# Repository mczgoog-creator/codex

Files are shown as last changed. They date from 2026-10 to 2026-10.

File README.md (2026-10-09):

# DRV8701 双电机驱动板 · Rev B

**12 V、39×60 mm、4 层、1.6 mm** 双电机驱动板。Rev B 重新安排了两路半桥、去耦和功率回路，并加入 TPS25910 主电源控制。每段线路、过孔和铜区均按明确坐标人工规划，未使用自动布线或路径搜索。

[网页端 KiCad 导入包](downloads/DRV8701_12V_KiCad5_Import.zip) · [完整工程和资料 ZIP](downloads/DRV8701_12V_EasyEDA_Pro.zip) · [工程说明](hardware/drv8701-dual-12v/README.md)

## 在嘉立创 EDA 专业版中打开

网页端请下载 **`DRV8701_12V_KiCad5_Import.zip`**，在开始页选择 **「导入 KiCad」**，直接选择 ZIP。按[官网指引](https://prodocs.lceda.cn/cn/import-export/import-kicad/index.html)，导入副本采用真实 KiCad 5.1 格式，并通过 KiCad 自带归档功能打包。步骤和导入后检查见[网页导入说明](hardware/drv8701-dual-12v/IMPORT_IN_WEB_PRO.md)。

原始 KiCad 9 工程和自带库也随包保存。`EasyEDA_Pro/DRV8701_DUAL_12V.eprj3` 是另供 V4.1+ 离线／半离线桌面客户端使用的文件夹工程；需保留整个目录，不能当作网页 `.epro` 文件导入。

## 本版变化

- 四组高边源极与低边漏极相邻，通过局部宽铜连接相节点；功率转层采用四孔阵列。公共供电在 C15 正极处汇合并向两路分配。
- 泵和内部电源去耦至芯片的关键连接留在顶层；VM 先到 C3/C10，再到芯片 VM 脚。SH 源参考采用独立细线返回高边源极焊盘。
- 新增 U6 TPS25910、SW1 和五个配套无源件。SW1 控制主电源，原 U5 继续控制 DRV8701 的 nSLEEP。原 38 个元件的取值保留；原有脚网络仅 P2.1 从 VM 改为新增电源入口 VM_RAW。

主电源连续额定 5 A，R12=40.2 kΩ 对应手册限流 4.5–5.5 A。主开关关闭时芯片仍消耗约 2.5 mA 典型／4 mA 最大，分压另约 90 µA；不提供电池物理隔离或反向电流阻断。开启主电源前应保持两路桥关闭，VM 稳定后再使能，详见[首次上电步骤](hardware/drv8701-dual-12v/FIRST_POWER_ON.md)。

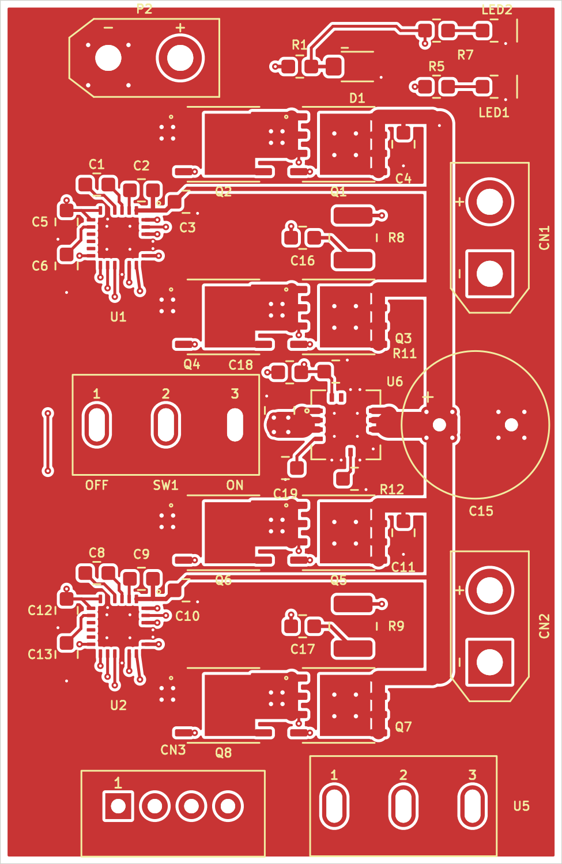
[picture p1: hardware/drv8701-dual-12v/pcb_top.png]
Rev B PCB 顶层预览


## 文件与检查边界

- [原理图 PDF](hardware/drv8701-dual-12v/DRV8701_DUAL_12V_schematic.pdf)、[PCB 各层检查图](hardware/drv8701-dual-12v/PCB_layers_review.pdf)
- [元件清单](hardware/drv8701-dual-12v/components.csv)、[采购约束](hardware/drv8701-dual-12v/procurement_notes.csv)
- [布局与电流路径说明](hardware/drv8701-dual-12v/source/engineering_review.md)、[主电源手册核对](hardware/drv8701-dual-12v/source/tps25910_power_control_review.md)
- [原图保留范围核对](hardware/drv8701-dual-12v/validation/rev_b_original_source_contract.json)、[交付检查记录](hardware/drv8701-dual-12v/validation/final_delivery.json)
- [独立布局几何检查](hardware/drv8701-dual-12v/validation/layout_geometry_audit.json)、[最后丝印与铜线复核](hardware/drv8701-dual-12v/validation/rev_b_final_silk_cleanup.json)、[Rev B 工程审计](hardware/drv8701-dual-12v/validation/rev_b_engineering_audit.json)

Rev B 共 **45 个元件、38 个网络、203 个唯一物理引脚／211 个焊盘实例、592 段线路、151 个过孔、12 个铜区**。冻结后的 KiCad 9 源板 **DRC 0 违规／0 未连接，原理图 ERC 0 错误／0 警告**。独立几何检查通过：14 条关键去耦连接均在顶层，最长 2.9713 mm；丝印与焊盘／过孔碰撞为 0，审核范围内的直角／锐角弯折为 0。

网页导入副本已通过真实 **KiCad 5.1.9：ERC 0 错误／0 警告，PCB DRC 0 错误／0 未连接**；45 个元件、38 网、203 脚逐值逐脚一致。PCB 检查已重填全部铜区并检查走线与填铜。副本的 624 段线路中，新增 32 段完全位于原 MOS 漏极焊盘铜内，新增实际铜面积为 0；原 592 段线路、151 孔、211 焊盘及 12 铜区保留。见[旧版最终等价核对](hardware/drv8701-dual-12v/validation/legacy5_final_pcb_equivalence.json)。

源软件检查不替代专业版实际导入检查。弯折统计排除同网焊盘／过孔内部和真实分支结点，具体范围见几何报告。五页 PCB 检查图、分层 PDF 及顶／底 SVG／PNG 均按冻结源板重新导出，来源 SHA 见[预览导出记录](hardware/drv8701-dual-12v/validation/preview_exports.json)。

桌面原生工程的[静态转换审计](hardware/drv8701-dual-12v/EasyEDA_Pro/native-final-audit.json) 已通过：元件／引脚／线路／过孔及 12 个填充铜区均与冻结源板对应，官方工程结构检查 0 错误／0 警告。未运行真实专业版桌面客户端，网页用户仍使用上面的 KiCad 导入 ZIP。

**真实嘉立创网页导入／DRC、样板通电和温升测试尚未完成。** 导入会重新铺铜，需复核四层各 35 µm 铜、功率铜区和规则。原图的 100 nF 电荷泵／内部电源去耦、较弱齐纳供电、IDRIVE 设置和无 GND 的控制插座仍保留，并在工程说明中列出。MOS 原厂手册已读取，采购需匹配普通 SOP Advance 封装；手册没有提供推荐 PCB 焊盘图。

## 来源与许可证

官方开源转换／校验工具保留各自的 Apache-2.0／MIT 许可证；上游地址与精确版本见[版本记录](hardware/drv8701-dual-12v/tools/easyeda-native/upstream-versions.json)。这些工具许可证不自动覆盖电路设计、第三方封装或厂商 PDF。原图、封装和手册来源见工程说明。

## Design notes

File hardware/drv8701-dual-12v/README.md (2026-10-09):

# DRV8701 双电机驱动板 · Rev B · 12 V

依据用户原始《8701驱动板（无电流检测2.0）.pdf》重建。本版重新安排半桥功率器件、去耦、供电和回流，并按用户后续要求加入主电源控制。**原 38 个元件的取值全部保留；原有引脚唯一授权网络变化是 P2.1 从 VM 改接 VM_RAW。** 原图其余连接保留，新增七件：U6、SW1、R10–R12、C18、C19。核对见 [rev_b_original_source_contract.json](validation/rev_b_original_source_contract.json)。

PCB 每个元件位置、线路、过孔和铜区边界均人工规划，未使用嘉立创自动布线器、其它自动布线器或路径搜索。脚本按明确坐标生成线路；铺铜填充只是按既定边界生成铜区。

## 打开工程与交付文件

用户使用嘉立创 EDA 专业版**网页端**。主要入口为 **`DRV8701_12V_KiCad5_Import.zip`**：在网页开始页选择 **「导入 KiCad」**后直接选择 ZIP。依据[官网指引](https://prodocs.lceda.cn/cn/import-export/import-kicad/index.html)，导入副本采用真实 KiCad 5.1 格式并由 KiCad 自带归档功能打包。步骤见 [IMPORT_IN_WEB_PRO.md](IMPORT_IN_WEB_PRO.md)。

原始 KiCad 9 源文件与库保留。桌面入口 `EasyEDA_Pro/DRV8701_DUAL_12V.eprj3` 由官方转换器及独立后处理生成，另供专业版 V4.1+ 离线／半离线客户端使用，需保留整个目录；不能当作网页 `.epro` 文件导入。

**尚未在真实嘉立创 EDA 专业版完成导入和 DRC。** 导入会重建铜区，需复核板框、叠层、功率铜区和设计规则。桌面文件的 schema／真实导出模板单位差异见 `tools/easyeda-native/RESEARCH.md`；首次打开应确认实际尺寸和规则值。

|文件|用途|
|---|---|
|`DRV8701_DUAL_12V.kicad_sch/.kicad_pcb/.kicad_pro`|Rev B 可编辑原理图、PCB、规则|
|`DRV8701_Custom.kicad_sym`、`DRV8701_Custom.pretty/`|本地符号及封装；配套库表同目录保存|
|`KiCad_Import_5/`|真实 KiCad 5.1 格式的网页导入副本|
|`imports/DRV8701_12V_KiCad5_Import.zip`|专用网页导入 ZIP|
|`EasyEDA_Pro/`|另供新版桌面客户端使用的文件夹原生工程|
|`DRV8701_DUAL_12V_schematic.pdf`|原理图阅读版|
|`PCB_layers_review.pdf`、`pcb_top/bottom.svg/.png`|从源 CAD 导出的各层检查图与顶底预览；底层 PNG/SVG 已镜像，按从底面观察显示|
|`components.csv`、`procurement_notes.csv`|元件值、封装及采购额定参数|
|`source/source_netlist.json`|原始 PDF 独立复核网表，作为原图基准保留|
|`validation/rev_b_original_source_contract.json`|原图取值、连接与授权主电源差异核对|
|`final_drc.json`、`validation/schematic_erc.json`|冻结后的 KiCad 9 DRC 与原理图 ERC|
|`validation/layout_geometry_audit.json`|独立读取实际 PCB 的路径、弯折、过孔与丝印检查|
|`validation/rev_b_final_silk_cleanup.json`|最终丝印调整与唯一最后铜线修改范围|
|`validation/rev_b_engineering_audit.json`|本版功率网络、填铜与工程审计|
|`validation/preview_exports.json`|本版预览与各层 PDF 的源板 SHA／导出记录|
|`source/engineering_review.md`|本版布局与电流路径说明|
|`source/tps25910_power_control_review.md`|主电源芯片手册、启动／限流／关闭状态核对|
|`FIRST_POWER_ON.md`|首次上电和两级开关操作步骤|
|`footprint_geometry.json`、`manual_routes.json`|封装依据及人工规划线路记录|
|`scripts/generate_schematic.py`、`tools/build_board.py`|原理图及明确坐标的 PCB 生成程序|
|`validation/`|本版最终检查记录|

用 KiCad 9 打开 `.kicad_pro` 即可读取同目录库。重建程序会覆盖其负责的设计文件，运行前应保存手工编辑副本。

## 尺寸、电流与布局

仅采用用户电机表格的 **12 V** 条件：每路较高档额定 0.4 A、堵转 1.8 A；电机路径按每路 1.8 A，公共供电／回流按合计 3.6 A 规划。堵转值用于短时最大电流初筛，不表示允许持续堵转。

本版 **39×60 mm、4 层、标称 1.6 mm**，元件全在顶面。四铜层均 **35 µm（1 oz）**，孔电阻计算假设成品孔铜至少 20 µm。名义叠层：两面阻焊各 0.01 mm、四铜层各 0.035 mm、两段半固化片各 0.20 mm、中芯板 1.04 mm，总厚 1.60 mm；板厂应据实际材料匹配成品规格。普通 R/C/LED 为 0603，R8/R9 为 1210，新增 C18 为 0805；没有小于 0402 的贴片。

|通路|本版设计|
|---|---|
|P2 至 U6、U6 至 C15 及两路主供电|外层公共主干 1.80 mm；C15 正极为汇合与分配点|
|In2.Cu 并行供电|4.6 mm VM 公共铜带与局部宽铜支路|
|高边 MOS 漏极|短 1.0 mm 外层支路，并由内层铜和四孔阵列连接裸露漏极焊盘|
|高边源极至低边漏极|相邻封装间的局部顶层宽铜，四组半桥均按相同结构安排|
|电机连接器|0.70 mm 外层主线，每个相节点配四孔功率阵列|
|低边 MOS 源极|短支线接本地宽铜，四孔阵列接地；F.Cu／In1.Cu／B.Cu 地铜提供并行回流|
|U6 IN／OUT|各三个并联引脚，每脚短 0.45 mm 连接接入公共铜；不是单根 0.45 mm 线路承担 3.6 A|
|信号与驱动支路|约 0.20–0.30 mm；这些线路不承担电机主电流|

IPC-2221 经验式 `I=k×ΔT^0.44×A^0.725`（A 为平方 mil）用于初筛。35 µm 铜、约 10°C 温升时，外层 1.8 A／3.6 A 线宽约 0.676／1.758 mm，内层约 1.76／4.57 mm，因此内层公共 VM 铜带取 4.6 mm。该经验式不计算实际板上的电流密度、开关波形或温升，成品仍需测量。

C15 安排在受控 VM 供电汇合处，两路从其正极向外分配。每组高／低边 MOS 旋转后令高边源极紧邻低边裸露漏极，以宽铜连接相节点。泵／内部电源去耦至芯片的关键连接留在顶层，VM 电源先进入 C3/C10 再到 VM 引脚；C4/C11 位于功率母线旁。SH 源参考采用独立细线返回高边源极焊盘，但栅极和参考线仍有转层，14 条关键连接静态路径的最大长度为 2.9713 mm、0 转层；GH1 约 19.22 mm、GH2 约 13.56 mm 且仍有转层，不能宣称全部驱动回路已最小化或开关振铃已验证。

制造规则最小间距／线宽 0.15 mm，普通信号孔 0.45/0.20 mm，最小钻孔 0.20 mm、最小环宽 0.10 mm。具体功率孔阵列和最终几何以本版检查报告为准。

## 主电源与接口

|位号|功能与引脚|
|---|---|
|P2|12 V 电源 XT30：1=VM_RAW 正极，2=GND|
|U6|TPS25910RSAR：IN 1/2/3=VM_RAW；OUT 10/11/12=VM；中心焊盘接 GND|
|SW1|主电源开关：2=PWR_EN，3=GND，1=NC；接通 2–3 时 U6 导通|
|U5|原 DRV8701 使能：2=NSLEEP，3=齐纳 3V3，1=NC；断开 2–3 时为休眠档|
|CN1/CN2|左／右电机 XT30：1=L_A/R_A，2=L_B/R_B|
|CN3|1=R_EN，2=R_PH，3=L_PH，4=L_EN；原图未设置 GND 引脚|

CN3 没有公共地针脚，控制器 GND 必须另外连接 P2 的 GND。SW1 是主供电控制，U5 是驱动芯片睡眠控制，二者不能混用。

TPS25910 工作电压 3–20 V、IN/OUT 绝对最大 22 V；本工程仅按 12 V 使用。连续额定 5 A，R12=40.2 kΩ、1% 对应限流 **4.5 A 最小／5 A 典型／5.5 A 最大**。这只是公共电源故障控制，不是两路电机各自的电流测量或斩波限流。3.6 A 时芯片导通损耗约 0.38 W 典型／0.54 W 最大，需要焊实中心接地焊盘并验证温升。

EN 为低电平有效。SW1 接通将 EN 拉地；断开时 R10=100 kΩ、R11=33 kΩ 分压产生约 2.98 V 高电平关闭。**关闭时 U6 自身仍消耗 2.5 mA 典型／4 mA 最大，分压另约 90 µA**。C15 储能和电机回馈可能使 VM 暂时有电；TPS25910 本身没有反向电流阻断，因此主开关不是电池物理隔离。长期存放应拔掉电源。

C19=10 nF 对 12 V 的理想上升时间约 **11.1 ms 典型**，按手册 8–15 µA 驱动电流初算约 **8.2–15.3 ms**。实际电容、输入电源、限流和热保护会改变或延长启动。手册 12 V 启动最小负载电阻为 12 Ω，接有 C15 时可用启动负载进一步减少；因此**开启 SW1 前保持 U5 休眠并令两路 EN=0，VM 稳定后再使能电机**。不得把典型上升时间当作控制器等待的保证值。

## PWM 与原图保留问题

按用户确认的 **不高于 20 kHz EN PWM** 使用，PH 固定方向。R8/R9=100 Ω、C16/C17=100 nF 串联 RC 保留；电阻采用 **1210、至少 0.5 W**。12 V／20 kHz 充分充放电模型每路约 0.288 W 上界、50% 占空比约 0.244 W。PH 周期翻转会产生更大的跨端阶跃，不能沿用该热假设。

|项目|保留的原图与影响|
|---|---|
|C2/C9 VCP–VM|100 nF，TI 推荐 1 µF；须检查泵纹波与驱动欠压|
|C5/C12 AVDD、C6/C13 DVDD|100 nF，TI 推荐 1 µF；须核查 LDO 稳定性和纹波|
|C1/C8 CPH–CPL|100 nF，与 TI 推荐值一致|
|VM 旁路|保留 100 nF 与公共 C15=470 µF；须测供电／再生电压|
|VREF／IDRIVE|各自接 AVDD；约 25/50 mA 源／灌，关闭高边 VDS 过流检测|
|SP／SN|接 GND；没有电机电流采样及各路可设斩波限流|
|nFAULT／SNSOUT／SO|原图 NC，控制器不能由这些脚接收原驱动器故障或采样信息|
|10 kΩ／齐纳 3V3|12 V 下假定 3.3 V 时总馈电约 0.87 mA；还供 LED 与 nSLEEP，须实测低电流工作点|
|CN3|无 GND 引脚，控制器另行共地|

布局重排和新增主开关没有修正上述原值与原连接。首次验证内容及顺序见 [FIRST_POWER_ON.md](FIRST_POWER_ON.md)。

## 焊接与采购复核

DRV8701 是 4×4 mm RGE24 VQFN、0.5 mm 脚距，中心地焊盘必须焊实。U6 是带中心地焊盘的 RSA16 VQFN。建议焊膏、预热和热风／手动回流；仅烙铁处理外围脚不能保证中心焊接。未填孔热过孔会吸锡，需检查浮高和空洞。

TPH1R403NL：1/2/3=S、4=G、5/6/7/8=D，中心裸露金属同属 D；高边裸露焊盘为 VM，低边为相节点，不能当作接地散热焊盘。原厂 **2026-04-14 Rev.3.0.A** 已读取：VDS 30 V、VGS ±20 V；10 V 下 RDS(on) 典型 1.2 mΩ／最大 1.4 mΩ，Qg 典型 46 nC、Qgd 典型 4.3 nC。引脚与普通 SOP Advance 的机械图已核对，详见 [原厂核对](source/tph1r403nl_manufacturer_review.md)。

该手册 p8 普通 SOP Advance 与 p9 SOP Advance(N) 不同，采购需匹配 p8。手册未提供推荐 PCB 铜焊盘图，外围 0.5×1.2 mm 焊盘是本设计尺寸。典型 Qg／原图 25/50 mA 的估算不替代最坏公差及实测 VGS。

SS12D10G4 的用户实测脚宽 1.3 mm、厚 0.8 mm，使用 2.3×1.1 mm 槽孔。C18 采购目标为 4.7 µF／50 V／X7R／0805，**须按具体料号的 DC 偏压曲线核对 12 V 下有效电容≥1 µF**；当前没有对某个采购料号完成该曲线验证。XT30、XH 实物外形、极性与 U6 钢网要求也应按采购品及厂商图复核。

## 来源与验证边界

- 原始 PDF：用户提供，见 `source/original_schematic.pdf`；原始网表见 `source/source_netlist.json`。
- TI DRV8701：[原厂手册](https://www.ti.com/lit/ds/symlink/drv8701.pdf)，SLVSCX5B，附原厂镜像 PDF `source/TI_DRV8701_SLVSCX5B.pdf`；镜像来自 [Tinkerforge](https://github.com/Tinkerforge/performance-dc-bricklet/blob/master/datasheets/drv8701.pdf)。
- TI TPS25910：`source/TI_TPS25910_SLUSAR6D.pdf` 与 EVM 手册；参数、封装及页码见 [主电源核对](source/tps25910_power_control_review.md)。
- Toshiba：[精确型号原厂 PDF](https://toshiba.semicon-storage.com/info/TPH1R403NL_datasheet_en_20191030.pdf?did=14296&prodName=TPH1R403NL)，本包为 Rev.3.0.A；MOS 封装几何另参考 [zdxddmx/smartcar-hardware](https://github.com/zdxddmx/smartcar-hardware) 的同型号原生库，交叉核对 [CaptainJaja/DRV8701_2Motors](https://github.com/CaptainJaja/DRV8701_2Motors)。未复用其它工程的 PCB 布局或布线。
- 官方转换／验证工具保留原许可证，上游 URL／commit 见 `tools/easyeda-native/upstream-versions.json`。

本版为 **45 个元件、38 个网络、203 个唯一物理引脚／211 个焊盘实例**，592 段人工指定线路、151 个过孔、12 个铜区。源 KiCad 9、KiCad 5 导入副本和桌面原生工程分别核对，各自结果保存于 `validation/`、`KiCad_Import_5/validation/` 和 `EasyEDA_Pro/native-*.json`，不沿用 Rev A 检查成绩。

冻结后的源板 KiCad 9 **DRC 0 违规、0 未连接**，原理图 **ERC 0 错误、0 警告**。独立 [布局几何审计](validation/layout_geometry_audit.json) 通过，14 条关键去耦连接全部顶层且 0 转层，最长 2.9713 mm；丝印与焊盘／过孔碰撞 0，审核范围内直角／锐角弯折 0。弯折分类排除同网焊盘／过孔内以及真实分支结点。最终 PCB SHA256 为 `daa3c5be68e8667a06f6da7ec5fd3c1238de758fb6982bcae6e130e6b8204989`。

[最终丝印复核](validation/rev_b_final_silk_cleanup.json) 确认最后铜修改仅把 C18.1 至 U6 IN 汇流处的一段 VM_RAW 输入颈缩由 0.9 mm 加宽到 1.8 mm；其它焊盘、过孔和铜区边界未在该步骤改变。R10 位号移至底层，其余位号在顶层；主电源／休眠开关说明与板名位于背面，开关 ON 仍对应右侧／pin3。功率铜区和原图差异另见 [Rev B 工程审计](validation/rev_b_engineering_audit.json)。

桌面原生工程 [native-final-audit.json](EasyEDA_Pro/native-final-audit.json) 已通过静态转换检查，源板 SHA 与冻结文件一致。45 件／38 网／203 个唯一脚、592 段线路、151 孔及 12 个实际填充铜区逐项对应；四层、叠层厚度、区优先级及直接焊盘连接参数保留。格式检查 4096 条外层记录有效，未映射类型／未解释失败均为 0；已知 schema 与真实导出差异单列，官方工程结构检查 0 错误／0 警告。**这些是文件级检查，实际专业版桌面打开与 DRC 未执行。**

网页副本已由真实 **KiCad 5.1.9** 检查：原理图 **ERC 0 错误／0 警告**，PCB **DRC 0 错误／0 未连接**。检查已重填全部铜区，并开启全部走线错误及走线与填铜检查。45 件及原值、38 网、203 个唯一脚（194 连接、9 NC）逐项一致。副本保留源板 592 段线路、151 孔、211 焊盘和 12 铜区，另加 32 段完全在 MOS 既有漏极焊盘铜内的连接段，使旧版识别原有铜连通；副本共 624 段、新增实际铜面积 **0.0 mm²**。新旧填铜缓存随软件版本不同，按源区边界／参数在旧版实际重填；审计见 [legacy5_final_pcb_equivalence.json](validation/legacy5_final_pcb_equivalence.json)。

原理图 PDF、五页 PCB 各层检查 PDF、各层独立 PDF 与顶／底 SVG／PNG 均已更新为冻结 Rev B，源板 SHA 与导出方式见 [preview_exports.json](validation/preview_exports.json)。底层预览已镜像；层 PDF 由源 CAD SVG 经矢量转换生成，以保留完整板框。

本交付没有生产下单或 Gerber 制造放行。**真实专业版导入、铺铜／DRC，以及样板启动、开关波形、温升和短时堵转测试未完成。** 静态格式或铜几何核对不能代替这些实测。

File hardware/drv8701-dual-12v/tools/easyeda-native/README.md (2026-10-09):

# 原生工程生成与审计工具

Node.js 18+。最终工程已生成时，不需要运行这些工具即可用专业版打开工程。

这些脚本使用嘉立创／EasyEDA 官方 KiCad→`.eprj3` 转换器，再做有记录的字段纠正。所有 PCB 走线、过孔、铺铜都来自已完成的源板；脚本不调用自动布线，也不寻找连线路径。

准备字段验证器的依赖：在本目录运行 `npm ci --ignore-scripts`。实际转换器无 npm 依赖。然后运行：

```sh
bash run-native-conversion.sh /path/to/drv8701-dual-12v /path/to/new-native-output
```

输出目录必须是新的。源文件包含 `DRV8701_DUAL_12V.kicad_sch` 与 `DRV8701_DUAL_12V.kicad_pcb`；逐物理脚独立网表默认读取 `validation/expected_physical_pin_nets.json`，器件位号和值读取 `design_netlist.json`。所有数量均从本次源设计计算，适用于新增主电源控制的 Rev B。脚本检查失败会以非零状态停止。

工程必须保留完整目录。这份 `.eprj3` 是可选桌面交付：解压后，在支持该目录格式的专业版 V4.1+ 离线／半离线桌面客户端打开 `DRV8701_DUAL_12V.eprj3`，不要单独移动索引文件。网页端使用主交付 KiCad 5 ZIP 和官方“导入 KiCad”入口，不能把 `.eprj3` 放入 `.epro` 文件选择器。实际客户端 CLI 验证需要 V4.1.60+。

验证层次：

- `native-format-validation.json`：外层记录与当前官方字段 schema；真实导出与最新 schema 的已知差异单列，未修改 schema。
- `native-net-equivalence.json`：原生原理图逐脚网络与独立源表一致性。
- `native-pcb-equivalence.json`：原生 PCB 逐脚网络、所有直线走线端点／宽度／层别、过孔几何、铺铜边界和已填多边形与 KiCad 源一致性；逐区比较 priority→POUR.order、直连／热焊模式、间距、热焊间隙／桥宽、最小细度和孤岛模式。
- 该 PCB 报告还独立比较本次源板全部焊盘的尺寸、世界坐标、角度、圆角、圆孔／长槽、镀孔状态及铜层，并比较物理叠层厚度。
- 焊盘阻焊／锡膏扩展按源板保存并逐项检查，不沿用官方转换器默认2mil阻焊扩展。
- `native-library-link-equivalence.json`：本次全部组件的原理图／PCB共用器件、符号、封装、Unique ID；所需库均内嵌。
- `native-final-audit.json`：动态核验全部位号、原理图与PCB器件值、物理脚与命名网数量，并绑定本次源文件 SHA-256。PCB器件值保存为独立 Name 属性，避免共用同一符号／封装的不同阻容值丢失。
- `native-conversion-evidence.json`：旋转纠正与焊盘世界坐标逐个验算。
- `native-design-rules.json`：0.15 mm 最小铜间距／线宽、0.20 mm 最小孔径、0.10 mm 环宽、0.45/0.20 mm 默认过孔，以及 VM/VM_RAW／电机输出／栅极／信号默认线宽。

文件格式审计不等同于实际客户端打开或其 DRC。本云环境没有安装嘉立创专业版桌面客户端，实际打开与 DRC 尚未运行。叠层 thickness 和 RULE 长度的最新官方字段说明与官方 V4.1.36 真实导出模板单位口径存在差异；生成文件采用与真实导出模板一致的 PCB mil 编码。请在客户端确认 1.6 mm／四层／每层35 µm铜，以及上述规则显示值。详见 `RESEARCH.md`。

Rev B 所有区域采用统一的 0.15 mm 间距和直接焊盘连接，适配脚本用官方默认 COPPER 规则保存该连接模式；thermal_gap=0.25 mm、thermal_bridge_width=0.5 mm 同时保留，但在直连模式下不生效。全部区域移除所有无连接孤岛，面积阈值因此不生效。源区参数若不一致、使用面积阈值移除孤岛或未支持的网格填充，脚本会明确拒绝。POUR.width 保留官方转换器说明的真实导出 mm 特例，SOLID fineness 与热焊长度采用 PCB mil；这些显示和重新铺铜行为仍需实际桌面客户端核验。

官方工具来源与锁定版本记录在 `upstream-versions.json`，对应许可证保留在各供应目录。上游源代码没有修改；本目录顶层脚本是独立后处理和审计代码。

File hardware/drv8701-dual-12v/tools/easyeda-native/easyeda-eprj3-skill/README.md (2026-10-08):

# easyeda-eprj3-skill

> 用 AI 或几条 Node 命令，生成可在 EasyEDA Pro（嘉立创 EDA 专业版）直接打开的 `.eprj3` 工程。

[English version](README_en.md) · **当前版本：1.7.3** · [更新记录](CHANGELOG.md)

---

## AI 一键安装口令

把下面这句话直接发给你的 AI 助手即可开始：

> AI 助手，请帮我把 https://github.com/easyeda/easyeda-eprj3-skill 和 https://github.com/easyeda/easyeda-pro-format-skill 安装到我的 AI 助手的 skill 目录（例如 Claude Code 的 `.claude/skills/easyeda-eprj3`），确认 Node.js ≥ 18，并初始化一个示例工程。

## 安装

- 需要 [Node.js](https://nodejs.org/) ≥ 18（已在 Windows 11 + Node 24 验证），**无需 npm 依赖**。
- 需要 EasyEDA Pro / LCEDA Pro **V4.1+** 离线客户端，只在最后一步 `open` 用到。

把仓库克隆到你使用的 AI 助手的 skill 目录里（下面以 Claude Code 为例）：

```bash
mkdir -p .claude/skills
git clone --depth 1 https://github.com/easyeda/easyeda-eprj3-skill .claude/skills/easyeda-eprj3
cd .claude/skills/easyeda-eprj3
npm test            # 可选：跑一遍完整回归测试，确认环境正常
```

> **放在哪里？** 这个 skill 应该放在 AI 助手的 skill 目录里，让 AI 能自动加载 `SKILL.md`。Claude Code 用 `.claude/skills/easyeda-eprj3`，Cursor、Copilot 等其他工具的具体路径见 [`install/`](install/README.md)。所有脚本都通过 `--dir <你的工程目录>` 指定生成目标；示例中的 `./myboard` 请换成你的真实工程路径。

> 不想敲命令？把本页复制给 AI，让它按上面的指引帮你安装、初始化并执行后续步骤。

## 快速上手

这个 skill 是给 AI 助手用的。你不需要记下面的脚本名，只要用自然语言描述电路/PCB 需求，AI 会按 [`SKILL.md`](SKILL.md) 自动调用对应脚本并生成工程。

### 1. 安装

见上方 [安装](#安装) 部分。一句话总结：Node.js ≥ 18，把仓库克隆到任意目录即可。

### 2. 跟 AI 描述你的需求

例如：

> 我要画一个 STM32F103C8T6 最小系统，3.3V 供电，带一个 USB 转串口、一个 LED 和一个按键。工程放在 `D:\boards\stm32-blink`，板子 50mm x 40mm。

AI 会追问缺的信息（元件型号、引脚、网络名、连接关系等），然后自动开始生成。

### 3. AI 内部执行流程

AI 会按下面顺序完成：

1. `init.js` 创建 `.eprj3` 工程（原理图 + PCB）
2. `load-library.js list` 查看内置预设库
3. `add-symbol.js` 放置原理图符号、电源、端口
4. `add-wire.js` / `add-netlabel.js` 连线并标注网络
5. `set-refdes.js` 整理位号
6. `add-footprint.js` / `add-track.js` / `add-via.js` / `add-pour.js` 做 PCB 布局布线
7. `validate.js` 验证工程格式
8. `open.js` 在 EasyEDA Pro 客户端打开

这些命令由 AI 自动运行；你不需要手动敲。

### 4. 验收

生成完成后，AI 会汇报：

- 工程路径：`<你的目录>/<项目名>.eprj3`
- 原理图：多少元件、网络、标注
- PCB：多少封装、走线、过孔、铺铜
- 验证结果：0 错误
- 是否已自动打开客户端

你只需在 EasyEDA Pro 里检查、微调即可。

> 完整示例见 [`examples/blink/`](examples/blink)；各 AI 助手的 skill 接入方式见 [`install/`](install/README.md)。

## 开发/进阶参考

想手动调用脚本、了解仓库结构或扩展 skill 的用户，请查看 [`docs/development.md`](docs/development.md)。

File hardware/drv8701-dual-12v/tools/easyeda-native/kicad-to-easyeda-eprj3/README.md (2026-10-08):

中文 | [English](README.en.md)

# kicad-to-easyeda-eprj3

将 KiCAD 工程文件转换为嘉立创EDA（EasyEDA Pro）的 eprj3 工程格式，并将 KiCad 库转换为嘉立创EDA库文件 `.elibz2`。Convert KiCAD project files to the eprj3 project format of EasyEDA Pro, and KiCad libraries to the EasyEDA Pro library format `.elibz2`.

## 功能

- **工程转换**：批量遍历目录下所有 `.kicad_sch` / `.kicad_pcb`，生成完整的 eprj3 文件夹工程（`<name>.eprj3` 索引 + `sch/` + `pcb/`）
- **库转换**：把一个目录下的全部 KiCad 库（`*.kicad_sym` 符号库 + `*.pretty/*.kicad_mod` 封装库）打包成一个嘉立创EDA专业版库文件 `.elibz2`

## 环境要求

- Node.js ≥ 18，无任何 npm 依赖。

## 用法

### 1) KiCad 工程 → eprj3 工程（批量）

```bash
node scripts/convert-kicad.js convert <KiCad工程目录> <输出目录> [--project-name <名称>]
```

案例 — 转换本仓库自带的示例工程：

```bash
node scripts/convert-kicad.js convert example/kicad/kicad-project ./eprj3 --project-name kicad-project
```

输出：

```text
Created eprj3 project at D:/…/eprj3
  sch: kicad-project.kicad_sch -> D:/…/eprj3/sch/Schematic1/P1.esch2
  pcb: kicad-project.kicad_pcb -> D:/…/eprj3/pcb/PCB1.epcb2
```

生成的工程可直接用嘉立创EDA专业版打开：`<输出目录>/kicad-project.eprj3`，内含 `sch/`（原理图）与 `pcb/`（PCB）。

- 两个目录按位置传入：第 1 个是 KiCad 工程目录，第 2 个是 eprj3 输出目录
- 工程目录下每个 `*.kicad_sch` 生成一张原理图（`Schematic1`、`Schematic2` …），每个 `*.kicad_pcb` 生成一块板（`PCB1`、`PCB2` …）

### 2) KiCad 库目录 → 嘉立创EDA库包 .elibz2

```bash
node scripts/convert-kicad-lib.js convert <KiCad库目录> <输出.elibz2> [--name <库名>]
```

案例 — 把符号库与封装库放进同一个目录后整体打包（目录扫描不递归，`.kicad_sym` 与 `.pretty/` 需是直接子项）：

```text
mylibs/
├── Device.kicad_sym
├── LED.kicad_sym
├── Resistor_SMD.pretty/
│   ├── R_0805_2012Metric.kicad_mod
│   └── …
└── LED_SMD.pretty/
    └── …
```

```bash
node scripts/convert-kicad-lib.js convert mylibs ./DeviceLED.elibz2 --name DeviceLED
```

输出：

```text
  sym lib: Device.kicad_sym (533 symbols)
  sym lib: LED.kicad_sym (63 symbols)
  footprint lib: LED_SMD.pretty (100 footprints)
  footprint lib: Resistor_SMD.pretty (67 footprints)
Wrote DeviceLED.elibz2: 596 symbols, 167 footprints (636245 bytes)
```

生成的 `DeviceLED.elibz2` 可通过嘉立创EDA专业版的库导入功能安装到本地库中。

- 扫描目录下所有 `*.kicad_sym`（符号库）与 `*.pretty/`（封装库，读取其中 `*.kicad_mod`），全部合并写入**一个** `.elibz2`
- `--name` 可选：覆盖包名（默认取输出文件名去掉 `.elibz2` 后缀）
- `.elibz2` 是 zip 压缩包，内含：
  - `device2.json` — 器件/符号/封装索引（uuid → 元数据）；符号 `docType:2`、封装 `docType:4`，每个符号自动生成一个器件条目
  - `<库名>.elibu` — 记录流（与 `.esch2`/`.epcb2` 同格式），每个符号/封装写成两段：`DOCHEAD+META` 与 `DOCHEAD+记录`
- 符号 `Footprint` 属性（如 `Resistor_SMD:R_0805`）与转换出的封装名匹配时，器件的 `Footprint` 属性自动关联到对应封装 uuid
- 电源符号（`symbol_type "power"`）的 META `docType` 写为 18；封装文档包含 19 层表 + `ACTIVE_LAYER` + 完整 `CANVAS`，且不带 `PART` 记录
- 示例：`example/easyeda/easyeda-pro-libs.elibz2` 为嘉立创EDA专业版导出的参考库包

## 转换覆盖范围（best-effort）

输出严格对齐 [easyeda-pro-format-skill](https://github.com/easyeda/easyeda-pro-format-skill) 的官方格式文档（types / 字段定义 / JSON Schemas），并以真实导出数据校准 schema 与实际导出不一致之处；可另参考 [官方 eprj3 格式示例工程](https://github.com/easyeda/easyeda-pro-eprj3-format)：

| KiCad | eprj3 |
| --- | --- |
| `lib_symbols`（原理图内嵌符号库） | `.esch2` 内嵌 `SYMBOL` 文档段（`PART`/图形/引脚）+ `DEVICE` 文档段 |
| `symbol` 实例（含 `property`、`mirror`） | `COMPONENT`（`partId` 指向内嵌 `PART`，`DeviceName` 指向 `DEVICE`，镜像/旋转已换算）+ `Designator`/`Value` `ATTR` |
| `wire` | `WIRE` + 多条共享 `lineGroup` 的 `LINE` |
| `bus` / `bus_entry` | `BUS` + `LINE` / `BUSENTRY` |
| `junction` | 填充 `CIRCLE`（电气节点） |
| `no_connect` | 两条 `LINE`（X 标记） |
| `label` / `global_label` / `hierarchical_label` | `NETLABEL` |
| `text` / `text_box` | `TEXT`（+ `RECT` 边框） |
| `polyline` / `rectangle` / `circle` / `arc` / `bezier` | `POLY` / `RECT` / `CIRCLE` / `ARC`（三点求圆心）/ `BEZIER`，stroke/fill 样式同步映射 |
| `image` | `OBJ`（base64 内嵌） |
| `sheet`（层次图） | `RECT` + 名称 `TEXT` + 引脚 `NETLABEL` |
| 引脚电气/图形类型 | `PIN.electric` / `PIN.pinShape` 数值映射 |
| `footprint`（含 `pad`） | `.epcb2` 内嵌 `FOOTPRINT` 文档段（`PART`/`PAD`/丝印图形）+ `DEVICE` 文档段 + `COMPONENT` 放置 + `Designator`/`Footprint`/`Device` `ATTR` |
| pad 网络 / 椭圆孔 | `PAD_NET`（绑定元件引脚）+ `NET` 索引记录 / `holeType ROUND` 宽高 |
| `segment` / `arc`（PCB 走线） | 对应层上的 `FILL`（直线为闭合细多边形；圆弧为带 `ARC` 段的闭合多边形） |
| `via` | `VIA`（网络/孔径/盘径） |
| `zone` | `POUR`（`pourType`/`keepIsland`）+ 每个 `filled_polygon` 合并出的 `POURED`（`pourFill`，head id 关联 `POUR`）；keepout → `REGION`（`regionType PROHIBIT` + `prohibitType`） |
| `dimension`（aligned/orthogonal/radial/leader） | `DIMENSION`（`dimensionType LENGTH-CONSTRAINT` + `controlDot`） |
| `gr_line` / `gr_arc` / `gr_rect` / `gr_poly` / `gr_circle` / `bezier` | `LINE` / `ARC` / 闭合 `POLY`（圆为 `["CIRCLE",…]` 路径、贝塞尔为 `"C"` 段路径） |
| `gr_text` | `STRING`（对齐 origin、镜像、knockout→reverse） |
| `gr_rect`/`gr_line`/`gr_arc`/`gr_poly` on `Edge.Cuts` | 拼接为 `POLY` `BOARD_OUTLINE`（`layerId=11`） |
| 层映射 | `F.Cu=1`、`B.Cu=2`、`F.SilkS=3`、`B.SilkS=4`、`F.Mask=5`、`Edge.Cuts=11`、`In{n}.Cu=14+n`…；PCB 文档写入官方 60 层表 |

- 单位换算：KiCad mm → eprj3 mil（×39.3700787）；坐标轴翻转：KiCad Y 向下 → eprj3 Y 向上；旋转角 (360−deg)%360
- uuid 关联（官方约定）：`.esch2` 页面 / `.epcb2` / `.ecfg` 的 `DOCHEAD.uuid` 分别等于索引中 `sheets` / `pcbs` / `schematics` 的 uuid
- 同时生成 `sch/<名称>/<名称>.ecfg`（设计规则骨架）与 `.evar`（装配变量，空）
- **不迁移**：3D 模型、网络类、SPICE 模型、自定义规则；无法翻译的元素会跳过并告警

### 库转换覆盖范围（.elibz2）

| KiCad 库 | .elibz2 |
| --- | --- |
| `*.kicad_sym` 内每个 `(symbol …)` | `SYMBOL` 文档段（`PART`/`PIN`/`POLY`/`RECT`/`CIRCLE`/`ARC`/`BEZIER`）+ `device2.json` 符号索引 + 器件条目 |
| `symbol_type "power"` | META `docType:18`（电源类） |
| 符号 `property`（Reference/Value 之外的） | 器件 `attributes` 透传 |
| 符号 `Footprint` 属性 | 与封装名匹配时自动写入器件 `attributes.Footprint`（uuid） |
| `*.pretty/*.kicad_mod` 每个 `(footprint …)` | `FOOTPRINT` 文档段（19 层表 + `PAD`/`POLY`/`ARC` + `ACTIVE_LAYER`）+ `device2.json` 封装索引 |
| pad `thru_hole`/`oval` 钻孔 | `PAD` 的 `holeDiameter`/`holeWidth`/`holeType ROUND` |
| `F.SilkS`/`B.SilkS` 图形 | layerId 3/4；Fab/CrtYd/Dwgs 等其余 → Document 层 13 |

## 目录结构

```
kicad-to-easyeda-eprj3/
├── scripts/
│   ├── convert-kicad.js      ← 工程批量转换入口（→ eprj3 工程目录）
│   ├── convert-kicad-lib.js  ← 库转换入口（→ .elibz2 库包）
│   └── lib/
│       ├── kicad.js          ← KiCad S-expression 解析器
│       ├── kicad-to-eprj3.js ← 符号/封装 → eprj3 记录
│       ├── eprj3.js          ← eprj3 读写核心（源自 easyeda-eprj3-skill，已按官方示例修正）
│       ├── elibz2.js         ← .elibz2 库包组装（device2.json + .elibu）
│       ├── zip.js            ← 零依赖 zip 读写（zlib deflate/store）
│       └── utils.js
├── example/
│   ├── easyeda/              ← 嘉立创EDA专业版参考库包 easyeda-pro-libs.elibz2
│   └── kicad/                ← 示例 KiCad 工程
└── test/
    ├── smoke.js              ← 端到端冒烟测试（68 项断言）
    └── validate-format.js    ← 用官方 JSON Schemas 校验生成记录的格式验证器
```

## 测试

```bash
npm test
```

另可用官方 Schemas 逐条校验生成的记录（sch/pcb/lib 三种上下文，lib 按文档 docType 自动路由）：

```bash
node test/validate-format.js <生成的 .esch2|.epcb2|.elibu> <sch|pcb|lib>
```

> 验证器依赖 [easyeda-pro-format-skill](https://github.com/easyeda/easyeda-pro-format-skill) 的 `validate.js`，默认在其同级目录查找；也可通过环境变量 `EASYEDA_FORMAT_SKILL` 指定路径。注：官方 Schemas 与真实导出数据存在少量出入（如 `POUR.pourType`、PCB `ATTR.groupID`、`DIMENSION` 结构等），验证器已按真实导出数据校准。

## 相关项目

- [easyeda-pro-format-skill](https://github.com/easyeda/easyeda-pro-format-skill) — 嘉立创EDA Pro 文件格式技能包（types 索引、图元字段定义、JSON Schemas、validate.js），本仓库的格式权威参考
- [easyeda-eprj3-skill](https://github.com/easyeda/easyeda-eprj3-skill) — 教 AI 编码助手从零生成 `.eprj3` 工程的技能包；本仓库的 `scripts/lib/eprj3.js` 与 `utils.js` 即来自该项目的核心库
- [easyeda-pro-eprj3-format](https://github.com/easyeda/easyeda-pro-eprj3-format) — 官方 eprj3 格式示例工程

## License

[Apache-2.0](LICENSE)

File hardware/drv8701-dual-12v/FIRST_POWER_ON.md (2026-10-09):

# Rev B 首次上电与开关顺序

本板按12 V、两路370电机设计。SW1控制TPS25910主供电，U5控制两个DRV8701的nSLEEP。两个开关作用分开：先建立VM电源，再使能驱动桥。

冻结后的源板KiCad9 DRC为0违规／0未连接、原理图ERC为0错误／0警告；网页副本也通过真实KiCad5.1.9 ERC 0错误／0警告、PCB DRC 0错误／0未连接。[独立布局检查](validation/layout_geometry_audit.json) 和 [最后丝印／铜线复核](validation/rev_b_final_silk_cleanup.json) 均通过，更新后的预览见 [导出记录](validation/preview_exports.json)。功率路径见 [Rev B工程审计](validation/rev_b_engineering_audit.json)。这些静态成绩不替代专业版导入检查或本页样板步骤。

## 通电前

1. 在导入后的专业版确认39×60 mm、四层35 µm铜和制造规则，重建铺铜并运行DRC。核对XT30正负极、MOS普通SOP Advance封装、VQFN中心焊盘和电解极性。
2. 先不接电机；SW1置于关闭，U5置于休眠档（断开2–3脚的3V3连接）。外部控制器的两路EN保持0；PH先固定方向，避免悬空输入。
3. 控制器GND另外接P2的GND。CN3只有四根控制信号，无地针脚。
4. 首次使用可限流的12 V电源，例如先限1 A检查空载板。P2.1是VM_RAW正极，P2.2是GND；不要将电源直接接入下游VM绕过U6。

## 检查主开关

|状态|预期与检查|
|---|---|
|SW1关闭|U6 EN由100 kΩ／33 kΩ分压拉高，12 V输入下约2.98 V；不再向VM提供正向电源。U6仍消耗2.5 mA典型／4 mA最大，分压另约90 µA。|
|SW1接通2–3脚|U6 EN接地，低电平有效，VM受控上升。C19=10 nF时理想上升时间约11.1 ms典型，按手册电流范围初算8.2–15.3 ms。|
|VM稳定后|才将U5切到唤醒档，检查nSLEEP和两只DRV8701内部电源，再逐步施加EN PWM。|

首次用示波器测VM上升和输入电流，确认没有反复启动／限流。限流、热保护和电容公差会延长上升时间，**不把11 ms典型值直接当作控制器等待保证值**。手册12 V启动最小负载电阻为12 Ω，带C15输出电容后可用启动负载还会降低；启动阶段应保持桥关闭，不边升VM边启动电机。

主开关没有反向电流阻断。关闭后C15储能和电机回馈可能使VM暂时有电，测量确认电压降低后再操作电路；长期存放应拔掉电池／电源。

## 检查原图保留节点

保持EN=0，检查两只DRV8701的AVDD、DVDD、VCP与VM差值以及nSLEEP。分别记录冷启动、睡眠和唤醒状态。原图VCP／AVDD／DVDD的100 nF低于TI推荐1 µF，需观察内部电源和电荷泵纹波／欠压，不仅检查直流平均值。

测齐纳3V3与nSLEEP实际电压。原图12 V经10 kΩ的总馈电仅约0.87 mA，还带LED与nSLEEP；不能把此节点当作其它控制器的3.3 V电源。原图nFAULT、SNSOUT、SO为NC，控制器不能依赖它们确认驱动器状态。

## 接入电机并逐步加负载

1. 断开主电源并确认VM下降，先接一路电机，另一接口留空。控制器PH固定、EN从低占空比开始；只用不高于20 kHz的EN PWM。
2. 在空载到额定负载间逐步增加，检查电机输出、VM、VGS／SH振铃和输入电流。高边VGS使用适当差分测量，不将接地示波器的地夹接在浮动高边源极上。
3. 单路验证后接双路，检查U6、MOS、R8/R9、连接器与供电线温升。R8/R9必须为1210且额定至少0.5 W。
4. 每路1.8 A、合计3.6 A仅按短时堵转初筛；不要无限期堵转。U6 4.5–5.5 A限流是公共输入保护，不提供每路电机电流检测。根据电机、板上温升和实测输入电流确定控制器的故障停止时间。

GH1仍约19.22 mm，栅极／SH跨层，不能仅凭源板DRC为零省略开关波形检查。应记录VM再生电压，TPS25910 IN／OUT绝对最大为22 V，MOS VDS绝对最大为30 V；再生工况要按实际电源和电机检查。

完整电气差异、封装和资料见 [README.md](README.md)，主电源计算见 [tps25910_power_control_review.md](source/tps25910_power_control_review.md)。这些步骤尚未在样板上执行；本交付没有通电或制造放行结论。

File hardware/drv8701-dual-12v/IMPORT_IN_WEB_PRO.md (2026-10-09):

# 嘉立创 EDA 专业版网页端导入 · Rev B

使用用户提供的[官方 KiCad 导入指引](https://prodocs.lceda.cn/cn/import-export/import-kicad/index.html)。该页面列出 KiCad 5.1／5.9 支持范围，要求使用 KiCad 自带归档功能打包，并说明导入后重新铺铜。

## 下载与操作

使用 **`DRV8701_12V_KiCad5_Import.zip`**：

- [从 GitHub 下载网页导入 ZIP](https://github.com/mczgoog-creator/codex/raw/refs/heads/main/downloads/DRV8701_12V_KiCad5_Import.zip)
- 完整工程包中也有同一文件：`imports/DRV8701_12V_KiCad5_Import.zip`。

ZIP 内为 KiCad 5.1 的 `.pro`、`.sch`、`.lib`、`.kicad_pcb`，包含缓存库、本地符号及封装库；保留完整 ZIP 直接导入。

1. 在嘉立创 EDA 专业版**开始页**选择 **「导入 KiCad」**。若文件选择器仅允许 `.epro`，返回开始页改选 KiCad 导入入口。
2. 选择 `DRV8701_12V_KiCad5_Import.zip`。不改后缀，不将 ZIP 中的单个文件取出再导入。
3. 打开导入后的原理图和 PCB，核对以下数据、重新铺铜并运行专业版 DRC。
4. 保存工程；需要专业版原生备份时，由专业版自身的工程导出功能生成。

`.eprj3` 是另供新版桌面客户端使用的文件夹工程，不是当前网页 `.epro` 选择器要求的文件。网页端优先使用上述 KiCad ZIP。

## 导入后核对

|项目|Rev B 预期|
|---|---|
|板框与叠层|39×60 mm，4 铜层，板厚 1.6 mm，各层铜 35 µm|
|元件与网络|45 个元件，38 个网络，203 个唯一物理引脚|
|主电源|P2.1=VM_RAW；U6 的 IN 接 VM_RAW、OUT 接 VM；SW1 仅控制低电平有效的 EN|
|原使能|U5 仍连接原 nSLEEP 网络，作用与 SW1 分开|
|控制插座|CN3：1=R_EN，2=R_PH，3=L_PH，4=L_EN；无 GND 引脚|
|功率线路|外层公共主干 1.80 mm、电机主线 0.70 mm、高边漏极支路 1.0 mm；In2.Cu 公共 VM 铜带 4.6 mm，并有局部功率铜区|
|普通规则|最小铜间距／线宽 0.15 mm，信号孔 0.45/0.20 mm；功率孔阵列按源板核对|
|地与相节点铜|F.Cu、In1.Cu、B.Cu 的 GND 铜；顶层相节点局部宽铜，以及 In2.Cu 的 VM 铜带／支路|

旧格式文件不携带现代详细介质叠层，原叠层另存于 `KiCad_Import_5/stackup-source.kicad-sexpr.txt`。请在专业版设置成品厚度、各层铜厚及板厂实际叠层；导入器可能不迁移全部制造规则。

官方导入会重建铺铜，因此要检查相节点宽铜连接、四孔阵列连接、各层地连续性、VM 铜带与信号间距，以及未连接项。重新填充铜区属于铺铜，不是自动布线。禁止用自动布线替换已经人工规划的线路。

## 核对范围与限制

原图 38 个元件的取值保留；原有 173 个物理引脚中，172 个网络不变，唯一授权变化是 P2.1 从 VM 改接 VM_RAW，以串入主电源控制。新增七件为 U6、SW1、R10–R12、C18、C19。见 [Rev B 原图范围核对](validation/rev_b_original_source_contract.json)。

冻结后的 KiCad 9 源板 DRC 为 **0 违规／0 未连接**，原理图 ERC 为 **0 错误／0 警告**。本版 [独立布局几何检查](validation/layout_geometry_audit.json) 通过：14 条关键去耦路径全在顶层、最长 2.9713 mm，丝印／焊盘／过孔碰撞 0，审核范围内不良弯折 0。检查范围、弯折排除和 [最后修改记录](validation/rev_b_final_silk_cleanup.json) 可逐项查看。

兼容副本已通过真实 **KiCad 5.1.9** 检查：原理图 **ERC 0 错误／0 警告**，PCB **DRC 0 错误／0 未连接**。PCB 已重填所有铜区，并开启全部走线错误、走线与填铜检查。45 个元件及原值、38 个网络、203 个唯一引脚（194 个连接、9 个 NC）全部一致。

旧副本保留源板 592 段线路、151 孔、211 焊盘和 12 铜区，另含 32 段位于 MOS 既有漏极焊盘铜内的连接段，共 624 段；独立几何证明新增实际铜面积 **0.0 mm²**，不改变外部布线。旧版按原铜区边界／参数实际重填，不能以新旧缓存字节相等代替铜几何核对。见 [旧版最终等价报告](validation/legacy5_final_pcb_equivalence.json) 和 `KiCad_Import_5/validation/` 的实际软件记录。功率网络与填铜审计见 [rev_b_engineering_audit.json](validation/rev_b_engineering_audit.json)。

另供桌面客户端的 `.eprj3` 已完成 [静态转换等价审计](EasyEDA_Pro/native-final-audit.json)，仍未在实际专业版桌面打开／运行DRC；它不替代本页网页导入ZIP。

当前没有用户已登录的专业版网页会话，**尚未在真实网页端完成最终导入和 DRC**。格式与源软件检查不替代专业版实际导入检查，也不代表样板通过上电／温升验证。第一次通电请按 [FIRST_POWER_ON.md](FIRST_POWER_ON.md) 操作；原图保留问题和元件采购要求见 [README.md](README.md)。

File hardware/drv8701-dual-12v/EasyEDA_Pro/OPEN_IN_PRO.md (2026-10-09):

# 打开 Rev B 工程

**网页端请使用上一级的 [IMPORT_IN_WEB_PRO.md](../IMPORT_IN_WEB_PRO.md) 和 `imports/DRV8701_12V_KiCad5_Import.zip`，在首页选择「导入 KiCad」。** 本目录另供支持文件夹工程的桌面客户端使用，不能交给网页端要求 `.epro` 的导入入口。

保留整个 `EasyEDA_Pro` 文件夹，在 **嘉立创 EDA 专业版 V4.1+ 离线／半离线桌面客户端** 中打开：

`DRV8701_DUAL_12V.eprj3`

索引引用同目录 `sch/`、`pcb/` 中的原生原理图、PCB、配置和变量文件，不能只复制索引。全部符号、封装及器件均已内嵌，没有外部器件库依赖。

本工程由官方 KiCad→原生转换器和独立后处理生成，全程未调用自动布线。Rev B 包含主电源 TPS25910 控制电路；原理图与 PCB 的全部 45 个位号及元件值均与当前设计清单一致。转换绑定源 PCB SHA256：

`daa3c5be68e8667a06f6da7ec5fd3c1238de758fb6982bcae6e130e6b8204989`

文件级核验已通过：45 元件、38 命名网络、203 唯一物理引脚／211 焊盘实例、592 线路段、151 过孔、12 铜区及 12 个已填铺铜多边形、4 条板框边。板框为 39 × 60 mm，启用四铜层。每个焊盘的尺寸、位置、旋转、钻槽、圆角、镀孔与阻焊／锡膏扩展，所有线路／过孔的网络及几何，铺铜边界与已填几何均逐项与最终源板比较一致。官方工程结构检查为 0 错误、0 警告；当前字段验证无未解释失败。

铺铜参数也已独立核对：4 个相位铜区与 5 个 VM 铜区为优先级 2，3 个 GND 铜区为优先级 0；全部采用焊盘直连 `DIRECT`，铜间距与最小填充厚度均为 0.15 mm，删除所有未连接孤岛。热焊盘参数仍保存源值，但在直连模式下不生效。

**实际专业版桌面客户端打开、重新铺铜及其 DRC 尚未在本云环境验证。** 最新官方字段说明与 V4.1.36 真实导出模板对规则长度／叠层厚度的单位说明存在差异，文件采用该真实导出模板的 PCB mil 编码；`POUR.width` 按官方转换器的真实导出例外使用 mm。首次打开至少确认：

- 板厚 **1.6 mm**，**4 个铜层**，各 **35 µm**。
- 最小铜间距及线宽 **0.15 mm**；最小钻孔 **0.20 mm**；最小环宽 **0.10 mm**。
- 默认过孔外径／孔径 **0.45 / 0.20 mm**。
- 上述铜区优先级、焊盘直连、0.15 mm 最小填充厚度及孤岛删除设置。

若显示值与上述数值不同，按实际客户端单位修正规则／叠层后再重新铺铜并运行客户端 DRC。源板填充铜几何已保留，客户端重填结果仍需确认。文件级核验记录见 [native-final-audit.json](native-final-audit.json) 和各 `native-*.json`，单位差异和转换边界见 [RESEARCH.md](../tools/easyeda-native/RESEARCH.md)。

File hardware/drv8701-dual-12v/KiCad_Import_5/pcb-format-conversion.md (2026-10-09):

# Rev B PCB 格式转换与铜几何核对

源板为 **39×60 mm、4 铜层、1.6 mm 板厚**，含 **45 个器件、38 个网络、211 个实体焊盘、592 条人工规划线段、151 个过孔和 12 个铜区**。转换保留位置、旋转、焊盘形状、钻孔、网络、线宽、层、铜区边界和参数，并建立 45 个原理图与 PCB 的实例关联。

兼容副本补充 **32 条**仅位于既有 MOS Drain 焊盘铜内部的 0.25 mm 短连接，使旧版本能正确识别焊盘重叠已有的连接；因此兼容副本总计 **624 条线段**。独立保守多边形包含证明确认新增实际铜面积为 **0.0 mm²**，原 592 条线段全部保留。全程未使用自动布线或路径搜索。

4 个电机相节点局部铜区的 priority=2，以及 3 个全局 GND 铜区的 priority=0，均精确保留；所有直接连接设置保留。真实 KiCad 5.1.9 原生重填后，12 个铜区均有实际填充。填充缓存具有版本差异，不宣称不同版本缓存字节或多边形完全相同。

实际 PCB GUI DRC 开启「重填全部铜区」「报告全部线路错误」和「检查线路对已填充铜区」后得到 **0 错误、0 未连接**。证据为 `validation/legacy5_drc.rpt`、`validation/legacy5_zone_refill.json`、实际运行截图与上级 `validation/legacy5_final_pcb_equivalence.json`。

KiCad 5 保存层数与总体板厚；35 µm 铜厚及详细介质叠层另见 `stackup-source.kicad-sexpr.txt`，导入后应在专业版核对制造叠层。

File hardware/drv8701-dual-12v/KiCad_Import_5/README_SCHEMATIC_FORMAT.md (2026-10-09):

# Rev B：嘉立创专业版网页端 KiCad 5 导入工程

本目录是从冻结的 Rev B KiCad 9 工程转换得到的真实 KiCad 5.1 工程。网页端请使用实际 KiCad 5.1 项目管理器「File → Archive Project」生成的 `DRV8701_12V_KiCad5_Import.zip`，通过「导入 KiCad」入口导入。不要修改后缀或将 `.pro` 当作 `.epro` 导入。

Rev B 有 **45 个实体元件、38 个具名网络、203 个唯一物理脚**；其中 **194 个已连接脚、9 个 NC**。U6 为 TPS25910RSA 主电源开关，新增 SW1、R10/R11/R12 和 C18/C19。原图 38 个元件的值保留；仅按最新授权将 P2.1 从 VM 改为 VM_RAW，插入主电源控制。设计连接以 `../design_netlist.json` 为准，原始 PDF 与原始源网表单独保留。

本目录 `.sch` 为 EESchema Version 4，`.lib` 为 Version 2.4，`.pro` 为 KiCad 5 INI。符号、缓存库和封装库均在工程内，原理图实例 UUID 的前 8 位对应 PCB 组件标识。

已在真实 Eeschema 5.1.9 打开并运行 ERC：**0 错误、0 警告**。实际导出的 `.net` 与设计网表逐脚、逐值一致，NC 脚已验证独立。证据为 `validation/DRV8701_DUAL_12V.erc`、`validation/legacy_net_equivalence.json` 和实际运行截图。

尚未在用户已登录的嘉立创专业版网页端执行最终导入与 DRC。官方导入器会重新铺铜，导入后须核对铜区、制造叠层与规则。

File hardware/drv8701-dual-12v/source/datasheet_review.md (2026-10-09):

# DRV8701 双电机板 · Rev B：手册核对与原图保留范围

原图驱动电路的连接和元件值按用户要求保留。用户随后授权Rev B加入主电源控制，因此原38件取值不变、原有引脚仅P2.1从VM改为VM_RAW，其余连接保持；新增U6、SW1、R10–R12、C18、C19。原图保留问题不因新开关或布局重排而解除。差异范围见 [rev_b_original_source_contract.json](../validation/rev_b_original_source_contract.json)。封装尺寸及额定耐压／功率可依据实际使用选择。

## 资料状态

- TI 官方原文：SLVSCX5B，2015-03，2015-07 修订。官网 https://www.ti.com/lit/ds/symlink/drv8701.pdf 。
- 首次访问TI官网受阻时，使用了Tinkerforge官方开源硬件仓库所附TI原厂文档镜像：https://github.com/Tinkerforge/performance-dc-bricklet/blob/master/datasheets/drv8701.pdf 。该说明记录读取来源，不表示当前所有厂商下载仍被阻止。
- 交付包内原厂文档镜像为 `TI_DRV8701_SLVSCX5B.pdf`。PDF SHA256：5993f171a311fa8403ba77d5921534348ffddbbcf0c5d59c00c46b074671d850。
- TPH1R403NL 精确 Toshiba 官方 PDF 已成功下载并读取：https://toshiba.semicon-storage.com/info/TPH1R403NL_datasheet_en_20191030.pdf?did=14296&prodName=TPH1R403NL 。实际 PDF 内容为 2026-04-14 Rev.3.0.A；交付文件 `Toshiba_TPH1R403NL_Rev3_0_A.pdf`，完整核对见 `tph1r403nl_manufacturer_review.md`。
- 第三方该器件KiCad工程供交叉核对：https://github.com/CaptainJaja/DRV8701_2Motors ，其中 `lib/TPH1R403NL.pretty/TPH1R403NL.kicad_mod`。这是第三方封装，不能代替Toshiba机械图。
- 最终 MOS 焊盘几何依据 https://github.com/zdxddmx/smartcar-hardware 内 `eda/ProPrj_DRV8701电机双驱.epro` 的精确型号嘉立创原生封装 `572e0c5f381c446594eedc8b8157fefb`；具体尺寸见交付包 `footprint_geometry.json`。仅复用库几何，布局与每段布线均另行人工规划。
- Rev B新增主电源使用TI TPS25910RSAR，已读取SLUSAR6D及EVM SLVU760A；引脚、RSA16封装、限流和启动要求见 [tps25910_power_control_review.md](tps25910_power_control_review.md)。

## 原图关键网络复核

根据原始 PDF 高清局部图复核，两芯片均：

- pin6 VREF = pin7 AVDD；pin12 IDRIVE = AVDD。
- pin20 SN = pin21 SP = GND；pin9 nFAULT、pin10 SNSOUT、pin11 SO 标NC。
- pin5、pin16、pin25 EP接GND；pin13 nSLEEP共同由独立3V3稳压与开关控制。
- 独立netlist复核已确证两路DVDD分开：L_DVDD、R_DVDD；AVDD及泵节点也分别独立。

## DRV8701E 引脚

1 VM, 2 VCP, 3 CPH, 4 CPL, 5 GND, 6 VREF, 7 AVDD, 8 DVDD, 9 nFAULT, 10 SNSOUT, 11 SO, 12 IDRIVE, 13 nSLEEP, 14 EN, 15 PH, 16 GND, 17 GH1, 18 SH1, 19 GL1, 20 SN, 21 SP, 22 GL2, 23 SH2, 24 GH2, 25 exposed thermal pad/GND。来源TI pp3–4。

## 原图与TI推荐的差别（保持原样，仅报告）

|项|源图|手册要求/说明|证据与影响|
|---|---|---|---|
|VCP储能 C2/C9|100nF，VCP–VM|1µF / 16V 陶瓷|TI p3/p4 外部无源表，p33布局；源图仅推荐值的1/10，电荷泵纹波/CPUV/栅极驱动应上电验证。|
|AVDD去耦 C5/C12|100nF|1µF、≥6.3V陶瓷|TI p3/p4、p22；不满足推荐去耦，LDO稳定性及调制纹波需测。|
|DVDD去耦 C6/C13|100nF|1µF、≥6.3V陶瓷|同上。|
|CPH–CPL C1/C8|100nF|100nF X7R，耐压≥VM|与手册匹配；12V采用25V/50V额定封装均可。|
|VM旁路 C3/C4/C10/C11|两只并联100nF|近端100nF + 至少10µF bulk|两只并联100nF不能替代bulk；原图共有470µF C15，应在布局中令其至两个H桥高电流回路短，实际电源线及再生下需验证。|
|IDRIVE|直接AVDD|25mA source / 50mA sink且关闭高边VDS OCP|TI p20表5与文字；源图保留，不能宣称高边OCP完整可用。低边OCP仍有。|
|VREF/SP/SN|VREF=AVDD, SP/SN=GND|不使用限流时就是此连接|TI p15 7.3.3；正确禁用电流斩波，无需采样电阻。|
|nFAULT/SNSOUT/SO|NC|nFAULT和SNSOUT为开漏输出，若使用需外部上拉；SO负载电容≤1nF|TI p4；未使用可以NC，设备不能向控制器报告故障/斩波/采样。|
|3V3稳压|VM→10kΩ→BZT52C3V3，另两路10kΩ+红LED及两芯片nSLEEP负载|独立稳压可避免用睡眠时关断的DVDD唤醒自身；低电流齐纳实际电压应验证|12V、假定3.3V时馈入0.87mA；两LED若Vf≈1.9V共耗0.28mA，两nSLEEP最小RPD64kΩ共耗0.103mA，齐纳仅≈0.49mA。BZT52C3V3的测试电流/低电流曲线尚待原厂手册确认；不能假定3.3V±标称公差成立。DRV8701 VIH≥1.5V / VIL≤0.8V（TI p7）。|
|信号4pin|R_EN,R_PH,L_PH,L_EN无GND|外部逻辑需要共同地参考|严格保留；接线说明要求控制器GND与电源接口GND共地，避免悬浮输入。|

## IDRIVE表（仅参考，不修改源图）

TI p20：<1kΩ→GND 6/12.5mA；33kΩ±5%→GND 12.5/25mA；200kΩ±5%→GND 25/50mA；悬空或>500kΩ→GND 100/200mA；68kΩ±5%→AVDD 150/300mA；<1kΩ→AVDD 25/50mA。只有最后一项关闭高边OCP。未来另行电气修订可200kΩ→GND维持原驱动电流并恢复高边OCP。本版仍按原图接AVDD。已读取的TPH1R403NL手册给出典型Qg=46nC（10V）；25／50mA一阶估算约1.84／0.92µs，低于TI典型tDRIVE约2.5µs，但Qg没有最大值保证，不能据此宣称最坏公差或实板VGS已通过。详见 [MOS原厂核对](tph1r403nl_manufacturer_review.md)。

## PCB布局依据

TI p33：VM–GND 100nF应尽量贴近pin1并以粗线/地平面到IC GND；bulk应靠近外部FET高电流回路；跨层时用多个过孔减小感抗；100nF CPH–CPL贴近pin3/4；VCP–VM电容贴近pin1/2；AVDD/DVDD去耦靠近pin7/8；SH1/SH2参考连接高电流相节点，门极线尽量短，避开不相关控制线。

Rev B静态几何核对：14条泵／电源去耦至芯片的关键路径全在顶层、0转层，最长2.9713 mm；供电显式路径先到C3/C10再到VM脚，C15正极是主供电汇合／两路分流点。每组高边源极与低边漏极由短直连和相节点宽铜相接，功率转层用四孔阵列。源参考独立回到源脚，但GH1约19.22 mm、GH2约13.56 mm且均有两个转层孔，仍需样板开关波形验证。详见 [实际布局审计](../validation/layout_geometry_audit.json)、[本版工程审计](../validation/rev_b_engineering_audit.json)。

TI附录RGE0024F：封装4×4mm，0.5mm pitch；PCB端子24个焊盘0.24×0.60mm，对侧端子焊盘中心距离3.8mm；EP为2.8×2.8mm，必须焊接。QFN中心焊盘无法只靠普通烙铁充分焊接，建议焊膏+热风/预热或手动回流。焊膏开窗采用分区，防漂浮/锡珠；可选0.2mm热孔，若非填孔会吸锡，应设计钢网开口绕开。

Toshiba 原厂 PDF 已确认 MOS pin1/2/3 source、pin4 gate、pin5/6/7/8 drain，中心裸露金属也是 drain；普通 SOP Advance 的 5×5 mm、1.27 mm 脚距、4.25×3.5 mm 裸露金属与现用封装相符。手册 p8 的普通 SOP Advance 与 p9 的 SOP Advance(N) 机械尺寸不同，采购须匹配前者。PDF 未提供推荐 PCB 铜焊盘图，现有外围焊盘为设计尺寸。不得将 FET 裸露 D 默认当 GND；高边裸露 D 属 VM，低边裸露 D 属电机相节点。

原厂电气表给出 VDS=30 V、VGS=±20 V 绝对最大值；10 V 栅压 RDS(on) 最大 1.4 mΩ，4.5 V 时最大 2.1 mΩ。典型 Qg 为 46 nC（10 V）／20 nC（4.5 V）、Qgd 4.3 nC，测试条件见新核对记录；这些电荷值没有最大值保证，驱动时间推算只能作为初筛，不能替代实际 VGS 与相节点波形测试。

## 线宽与电流

只考虑12V 370电机：额定0.3/0.4A，每路最大堵转1.8A，两路公共电源3.6A。以更高12V档做设计；不为24V档加大线宽。

IPC-2221近似公式 I=k ΔT^0.44 A^0.725，A[平方mil]；外层k=0.048，内层k=0.024。35µm≈1oz铜厚。

|电流|外层10°C温升|外层20°C温升|内层10°C|内层20°C|
|---|---:|---:|---:|---:|
|0.4A|0.085mm|0.056mm|0.221mm|0.145mm|
|1.8A|0.676mm|0.444mm|1.758mm|1.154mm|
|3.6A|1.758mm|1.154mm|4.573mm|3.003mm|

建议外层每电机电流通路0.70mm，公共VM/GND1.80mm或等效宽度连续铺铜；若长线改为内层需按内层数值，不能复用外层宽度。芯片/FET焊盘出口短颈缩与过孔是局部限制，宜短颈缩、铜皮包覆、多个并联过孔；电流线不能经QFN窄焊盘传输。此经验式提供温升初筛，不替代实板验证或IPC-2152对具体堆叠的分析。

本版按上述条件采用外层电机0.70 mm、公共主干1.80 mm、In2.Cu公共VM铜带4.6 mm和F/In1/B地铜。最后将C18.1至U6 IN汇流段由0.9 mm加宽为1.8 mm，见 [最终修正记录](../validation/rev_b_final_silk_cleanup.json)。冻结后的KiCad9 DRC为0违规／0未连接，原理图ERC为0错误／0警告；该成绩不替代真实专业版导入与通电测试。

## 原图RC吸收功率（保持值，选合适封装）

两组电机跨端串联100nF+100Ω，τ=10µs。若标准DRV8701E EN-PWM慢衰减，电机端电压每周期0↔12V，频率20kHz、50%占空比：P_R=C V² f·tanh(T/(4RC))≈0.244W；充分充放电上界0.288W。高频极限约V²/(4R)=0.36W，故R8/R9建议1210且额定≥0.5W（原100Ω不变）。0603/0805一般0.1/0.125W额定不足。若PH每周期强制翻转产生−12↔+12V，功率约4倍，需要不同功率封装并实测；原4pin正常使用应PH固定方向、EN输入PWM。

## 仍需完成

1. 采购时匹配原厂 p8 普通 SOP Advance 封装，并核对实际焊接工艺。原厂电气和机械手册现已读取；推荐 PCB 铜焊盘图未包含在该手册中。
2. 在真实嘉立创 EDA 专业版客户端中确认打开、尺寸、叠层和规则单位，重建铺铜并运行 DRC。
3. 上述核实完成后制作样板；先保持U5休眠／两路EN=0启动SW1，VM稳定后再使能电机；按 [首次上电步骤](../FIRST_POWER_ON.md) 测VM启动、冷启动、睡眠／唤醒和1.8A瞬时负载下的AVDD／DVDD／VCP与3V3／nSLEEP；nFAULT可用临时测量，不添加板上连接。
4. 按实际PWM频率和模式测试R8/R9温升及MOS开关波形，检查原图电容值下是否CPUV触发。制造完成不等于电气规格已实测通过。

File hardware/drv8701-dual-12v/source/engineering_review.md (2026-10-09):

# Rev B 布局与电流路径说明

对象为 **39×60 mm、4 层、1.6 mm、各铜层35 µm** 的冻结版 Rev B。PCB SHA256：`daa3c5be68e8667a06f6da7ec5fd3c1238de758fb6982bcae6e130e6b8204989`。本文结合 [独立布局几何审计](../validation/layout_geometry_audit.json) 说明实际路径与手册初筛，并通过 [Rev B 工程审计](../validation/rev_b_engineering_audit.json) 核对功率网络和填铜。未使用自动布线或路径搜索，所有元件、线段、过孔和铜区边界由明确坐标人工规划。

## 原图范围与新增电源

本版45个元件、38个网络、203个唯一物理引脚／211个焊盘实例，592段人工指定线路、151个过孔、12个铜区。MOS重复裸露Drain焊盘计入实例，未重复计入唯一引脚。原图38个元件的值保留；原有173个引脚中172个网络保持，唯一授权变化为 P2.1 的 VM→VM_RAW。U6、SW1、R10–R12、C18、C19 共七件构成主电源控制，连接范围见 [原图差异核对](../validation/rev_b_original_source_contract.json)。原图泵／LDO电容、齐纳供电、IDRIVE、nSLEEP和四针控制接口没有随布局重排改变。

供电次序为 `P2正极 → VM_RAW → U6 IN/OUT → VM → C15正极 → 两路半桥`。新增主电源只控制输入正向供电，U5仍控制nSLEEP。TPS25910连续额定5 A，R12=40.2 kΩ限流为4.5–5.5 A；负载路径按双电机合计3.6 A短时堵转初筛。限流最大值不是可持续工作电流，主开关也不是物理隔离或反向阻断。

## 功率器件相邻关系与公共供电

四组半桥中的高／低边MOS均旋转270°，高边源极三脚紧邻低边裸露漏极。原来分开的两个功率端通过短支线及局部宽铜汇合；跨越2.46 mm封装间隙；每组半桥的三个源脚还各有0.40 mm宽的直连线路，共12条直连桥。源脚至低边漏极的直接连接同时由实际填充后的相节点铜支撑，不以铜区外框代替填充结果。四个相节点均用顶层宽铜和四孔阵列连接0.70 mm底层电机主线。

C15的正极焊盘位于 `(27.5,29.5) mm`，是受控VM的实际汇合／分流点：U6输出的1.80 mm主干在此进入，再向两路功率母线分配。电容不再作为远端支线末端。In2.Cu提供4.6 mm宽的公共VM铜带；各高边裸露漏极旁另有宽铜支路和四孔阵列连接。

|路径|Rev B几何与用途|
|---|---|
|公共电源|P2至U6、U6至C15及分配主干采用1.80 mm外层线，另有4.6 mm内层VM铜带|
|高边漏极供电|1.0 mm短外层支路、0.9 mm引脚汇流段、裸露漏极四孔阵列及内层VM铜区|
|高边源极／低边漏极|局部顶层相节点宽铜；三个源脚用短0.50 mm支线接汇流区|
|每路电机输出|0.70 mm底层主线，四个相节点均采用四孔阵列转层|
|低边源极回流|短0.50 mm源脚支线进入局部宽铜和四孔阵列，并接入地平面|
|U6 IN／OUT|三个引脚各以短0.45 mm线接入公共汇流铜；三支并联，不能按单根0.45 mm独承3.6 A理解|

35 µm铜、约10°C温升的IPC-2221经验式初筛：外层1.8 A约0.676 mm，3.6 A约1.758 mm；内层3.6 A约4.573 mm。因此外层电机／公共主线分别取0.70／1.80 mm，内层公共VM铜带取4.6 mm。经验式不替代成品板温升或电流密度场验证，芯片引脚附近的短并联支路也不能简单等同长单根线路。

## 过孔与地回流

每个相节点、高边裸露漏极和低边源极均配置四孔阵列，功率孔外径／孔径为0.65／0.30 mm，阵列有明确的两侧铜汇流连接。不是仅增加互不连接的孔。P2地、C15地及主电源入口转层也使用局部功率孔阵列。

以1.6 mm板、成品孔铜20 µm初筛，单个0.30 mm孔铜截面约0.01885 mm²，四孔合计约0.0754 mm²；单孔电阻约1.46 mΩ。均流理想模型下，1.8 A总电流通过四孔时各孔约0.45 A，总损耗约1.2 mW。实际电流不会保证精确均分，仍须匹配成品孔铜并测温。

F.Cu、In1.Cu、B.Cu均有GND铜；In1.Cu保留专用地平面，没有信号线路切割。F/B外层铜与接地阵列提供并行路径。本版填铜后In1.Cu为单个连续外轮廓，面积约2082.45 mm²；在y=3.15–50.05 mm区间按0.1 mm步长扫描，最小总截面宽约28.25 mm、最小最长连续段约8.634 mm，超过35 µm内层3.6 A初筛所需4.573 mm。此扫描是静态平面几何证据，不是电流密度或热仿真。CAD铜厚也不规定实际电镀孔铜，孔电阻计算另依赖成品孔铜≥20 µm。

名义叠层为两面阻焊各0.01 mm、四铜层各0.035 mm、两段prepreg各0.20 mm、core1.04 mm，总计1.60 mm。板厂实际材料应匹配成品板厚和铜厚；这不是已确认的生产叠层。

## 去耦、栅极与源参考

泵／内部电源去耦到芯片的关键连接留在顶层，不经过转层孔。VM支路先进入C3/C10正极，再直接连接DRV8701的VM脚；不能仅按电容与芯片的直线距离判断回路。C4/C11安排在功率VM母线附近，C15在公共供电汇合处；这几类电容的作用和路径分别核对。

C1/C8的CPL／CPH、C2/C9的VCP／VM、C3/C10的VM、C5/C12的AVDD和C6/C13的DVDD共14条关键连接应以顶层连通路径审计；静态审计确认这14条路径均在顶层且0转层，最长2.9713 mm；这些结果针对实际铜路径，不是器件中心直线距离。AVDD到IDRIVE的独立支路可转层，不与本地LDO去耦路径混淆。

SH1／SH2以独立0.20 mm细线返回高边实际源极焊盘，并与0.70 mm电机主电流路径区分。GL/GH线路约0.25 mm，使用In2.Cu或B.Cu。高边源参考的取点已独立返回源脚，但不能把它描述成所有驱动回路均已完成最小面积的成对Kelvin布线：GH1约19.22 mm、对应SH1约15.95 mm；GH2约13.56 mm、对应SH2约13.11 mm，每条栅极／源参考路径仍有两个转层孔。GH2主要在In2.Cu、源参考主要在B.Cu；GH1与SH1虽都主要在B.Cu，仍未全程成对相邻。应在12 V／实际PWM下测量VGS、SH与VM振铃。

原图VCP、AVDD、DVDD仍为100 nF，而TI推荐1 µF；原图IDRIVE接AVDD约25／50 mA且关闭高边VDS过流检测。重排布局不能消除这些电气差异。Toshiba已读取的精确原厂手册提供普通SOP Advance机械图，但未提供推荐PCB铜焊盘图；采购封装和焊接仍须复核。

## 主电源启动与验证

C19=10 nF控制U6的输出上升，12 V下理想模型为11.1 ms典型、约8.2–15.3 ms区间。功率限制、热保护、电容公差和电源条件可改变或延长启动。TI手册给出12 V启动最小负载电阻12 Ω，带输出电容后可用启动负载更小；因此接通SW1前应保持U5休眠、控制器两路EN=0，待VM实测稳定后再唤醒和施加PWM。

关闭SW1后，U6仍有2.5 mA典型／4 mA最大待机电流，分压另约90 µA；C15与电机再生可能使VM暂时保持有电。主电源手册详情见 [tps25910_power_control_review.md](tps25910_power_control_review.md)，操作顺序见 [FIRST_POWER_ON.md](../FIRST_POWER_ON.md)。

冻结后的KiCad9源板DRC为0违规／0未连接，原理图ERC为0错误／0警告。独立几何审计passed=true：14条关键去耦路径已全部测量，最长2.9713 mm、均顶层且0转层；丝印与焊盘阻焊开口／所有通孔过孔铜圆的碰撞为0；审核范围内直角／锐角弯折为0。弯折分类排除同网焊盘或过孔内部和真实分支结点，不能将该统计解释为每个汇流阵列外框都没有直角。

[最后修改记录](../validation/rev_b_final_silk_cleanup.json) 确认最后铜几何修正仅将C18.1到U6 IN汇流铜的一段VM_RAW输入线从0.9 mm加宽至1.8 mm。其它焊盘、孔与铜区边界保持，随后重新运行了源板DRC和独立几何审计。

桌面格式 [转换审计](../EasyEDA_Pro/native-final-audit.json) 已通过：12个铜区的边界、实际填充铜、优先级及直接焊盘连接参数与冻结源板对应，元件／脚／线路／孔等价，官方工程结构检查0错误／0警告。4096条外层格式记录有效，未解释失败／未映射类型均为0，已知schema差异另有记录；真实桌面打开／DRC未执行。

KiCad5副本已通过真实5.1.9的ERC 0错误／0警告、PCB DRC 0错误／0未连接；全部铜区重填并检查全部走线错误和走线对填铜。45件／38网／203脚逐项一致，源592段／151孔／211焊盘／12铜区保留；额外32段仅位于原MOS漏极焊盘内，旧副本总624段，新增铜面积0.0 mm²。详情见 [旧版最终等价报告](../validation/legacy5_final_pcb_equivalence.json)。

五页PCB检查图、分层PDF与SVG／PNG均按冻结源板更新，源SHA记录于 [preview_exports.json](../validation/preview_exports.json)。真实嘉立创网页导入／铺铜／DRC、样板开关波形、启动、温升和短时堵转尚未完成，静态几何审核不等同制造放行。

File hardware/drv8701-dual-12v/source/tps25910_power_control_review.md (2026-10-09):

# Rev B 主电源控制：TPS25910RSAR

本次用户要求加入主电源控制，因此在 P2 正极与原图的 VM 母线之间加入 U6 TPS25910RSAR。P2 正极改为 VM_RAW；原有 DRV8701、MOS 桥、470µF C15、3.3V 稳压支路和指示灯均接在受控 VM 下游。原来的 U5 继续控制两路 nSLEEP。新增 SW1 只操作 U6 的 EN，不承受电机功率电流。

核查依据为 TI 官方数据手册 [TI_TPS25910_SLUSAR6D.pdf](TI_TPS25910_SLUSAR6D.pdf)，SLUSAR6D，2014 年 1 月修订；其中封装附图 RSA0016B 更新为 4219093/A、2021 年 8 月。另核对 [TI_TPS25910EVM_SLVU760A.pdf](TI_TPS25910EVM_SLVU760A.pdf)，SLVU760A，2013 年 1 月修订，第 3 页原理图。

## 电源路径和额定参数

- IN 端 1、2、3 脚并联接 VM_RAW；OUT 端 10、11、12 脚并联接 VM。芯片工作电压为 3–20V，IN/OUT 绝对最大值为 22V，本工程仅按 12V 电机设计。
- 5、6、8、9、13、14 脚均接 GND；EVM 原理图明确将 PWPD 17 连接到 GND，故暴露焊盘 17 也接地，并使用接地导热过孔。
- 连续输出电流额定为 5A。按两路电机同时堵转合计 3.6A 检查功率路径；这不是允许持续堵转的工作方式。
- R12=40.2kΩ、1% 接 ILIM 至 GND。数据手册第 4 页对 40.2kΩ 给出限流值 4.5A 最小、5A 典型、5.5A 最大。该限流用于主电源故障控制，不替代原图缺失的电机电流检测。
- 导通电阻典型 29.5mΩ、最大 42mΩ，在数据手册所列 1–4.5A 条件下，3.6A 对应损耗典型 0.382W、最大 0.544W。必须将中心焊盘焊实，并通过四层接地铜和过孔散热；手册的 34.8°C/W 来自 JEDEC 高导热参考板，不能直接当作此成品板的实测热阻。

## 主开关逻辑与关闭状态

EN 为低电平有效。SW1 接通时将 EN 接地，U6 导通；SW1 断开时，由 R10=100kΩ、R11=33kΩ 分压将 EN 拉高。忽略芯片内部高阻分压时，12V 输入产生约 2.98V EN；已超过最坏 1.75V 关闭门限，并处于 EN 推荐 0–5V 范围。芯片内部 10MΩ/16.8MΩ 分压和输入偏置只产生较小修正。

关闭主开关后，下游 VM 不再从 VM_RAW 获得正向供电。U6 自身仍连接输入，其关闭偏置电流为 2.5mA 典型、4mA 最大，外部分压另约 90µA。C15 的储能需要时间释放，电机转动也可能通过桥臂二极管向 VM 回馈；因此关闭开关后 VM 并非立即降为 0V。TPS25910 自身没有反向电流阻断，数据手册第 14 页的反向保护应用需要另加外部 MOS 管，本版本没有该附加器件。

## 受控启动和电机使能顺序

C19=10nF、50V C0G 接 GATE 至 GND。第 7、11 页公式给出：

`dVM/dt ≈ IGATE / (C19 + CINT)`，其中 CINT 典型 200pF、IGATE 典型 11µA。

12V 上升时间典型约 `(10nF+0.2nF)×12V/11µA = 11.13ms`。470µF C15 对应典型充电电流约 `470µF×11µA/10.2nF = 0.507A`，其余 VM 陶瓷电容增加少量负载。第 4 页在 V(GATE−OUT)=3.5V、EN 为低的测试条件下，IGATE 规定为 8–15µA；该范围对应理想模型 8.16–15.3ms，实际输入电源、电容容差和功率限制仍会改变启动波形。

手册第 17 页明确给出最小启动负载电阻 `RMIN=VIN²/12`，12V 时为 12Ω；输出电容存在时，可允许的启动负载还会减小。因此在接通 SW1 前，应将 U5 置于休眠状态，或由控制器保持两路 EN=0，并保持到 VM 稳定后再使能电机。应在样板上测量 VM 上升和输入电流，再确定控制器的启动等待时间。

## 输入去耦 C18

C18 采用新增 4.7µF、50V、X7R、0805 封装，紧邻 U6 的 IN/GND 连接。`12V 偏压下有效电容 ≥1µF` 是本设计的采购目标；TPS25910 数据手册没有规定 1µF 的数值下限，官方 EVM 输入侧采用 0.1µF 陶瓷与 47µF 电解的组合。

当前没有获得具体 4.7µF/50V/0805 采购型号的制造商 DC 偏压曲线，因此未将某个料号的有效电容标为已验证。采购时需查对应料号的 DC 偏压曲线，并计入公差和温度影响满足上述目标。不能仅凭标称电容和耐压推定 12V 下仍有 4.7µF。

## 封装核查

TPS25910_RSA16 的铜焊盘按 TI 推荐板级图生成：四边引脚中心间距 0.65mm，对边焊盘列中心距 3.8mm，周边焊盘 0.60×0.31mm，圆角半径 0.05mm，中心焊盘 2.7×2.7mm。全部 17 个焊盘的位置、尺寸及针脚顺序已独立核对，见 `validation/tps25910_footprint_review.json`。

目前封装的中心焊盘为整面焊膏开口。TI 模板图建议中心焊膏分为四个 1.19×1.19mm 窗口，中心偏移分别为 ±0.695mm。采用手工涂膏与热风焊接时应控制中心焊盘的焊膏量；若制作钢网，应按该四窗口图调整中心焊膏层。

## 文件校验

- TI 数据手册 SHA-256：`b2b1c899abf10f42a9090d0a94f9fc63376bdbb19300fd42c2c5bfa1f8fd56de`
- TI EVM 手册 SHA-256：`5b2f6dd78907d0bf8cf0c8f1e942d8a5bddc5b56714582ede7d8b2ecbfbe43db`

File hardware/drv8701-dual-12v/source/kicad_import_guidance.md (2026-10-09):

# 官方 KiCad 导入指引核对

来源：<https://prodocs.lceda.cn/cn/import-export/import-kicad/index.html>
读取日期：2026-10-09。本文只转录本次导入方案有关的官方要求。

- 「嘉立创EDA专业版支持导入 KiCad 5.1 和 KiCad 5.9 版本的格式文件。」
- 「在KiCad打开工程后，在顶部用压缩功能进行打包」，在专业版开始页导入 ZIP。
- 「KiCad 工程压缩请使用 KiCad 自带的打包功能，不要自行在文件夹打包，因为自带的打包功能会把原理图使用的库文件也自动打包。」
- 「PCB 导入后会自动重建铺铜，铺铜结果会有差异，请仔细检查。」

用户确认使用嘉立创 EDA 专业版网页端。网页端的「导入 KiCad」入口与「导入嘉立创 EDA 专业版」入口不同；本次采用前者。`.eprj3` 是另一种新版桌面文件夹工程，不能直接作为网页端 `.epro` 导入文件，也不能通过改名转换。

原始可编辑源工程来自 KiCad 9，不能仅将 ZIP 或文件版本标记改名来宣称支持旧版导入；本次另行产生真实 KiCad 5.1 格式的 `.pro/.sch/.lib/.kicad_pcb` 与本地封装库，并记录转换检查。

自动重建铺铜属于已定义铜区的填充，不是自动布线。本工程的元件布局与每段铜线均人工规划，未调用自动布线器。

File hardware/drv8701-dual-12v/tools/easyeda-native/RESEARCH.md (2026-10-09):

# 嘉立创 EDA 专业版文件路径与验证研究

更新时间：2026-10-09。仅研究与文件生成，没有调用自动布线。2026-10-08 的 Rev A 探针保留为历史工具验证，当前最终结果为文末的 Rev B 核验。

## 官方来源

- 官方 AI/API SDK：<https://github.com/easyeda/easyeda-api-sdk>
- 官方 API 技能与完整 API 参考：<https://github.com/easyeda/easyeda-api-skill>
- 官方桌面 CLI 文档：<https://github.com/easyeda/easyeda-client-cli>
- 官方当前原生格式、JSON Schema、验证器：<https://github.com/easyeda/easyeda-format-skill>
- 官方 `.eprj3` 格式与真实导出样例：<https://github.com/easyeda/easyeda-pro-eprj3-format>
- 官方 KiCad → 原生 `.eprj3` 转换器：<https://github.com/easyeda/kicad-to-easyeda-eprj3>
- 官方原生工程结构验证器：<https://github.com/easyeda/easyeda-eprj3-skill>
- 旧 V3 格式：<https://github.com/easyeda/easyeda-file-format>

转换器校验版本：`a16545dd7922455e6a20f69adeb234c924af08b5`。
转换器自带测试：2026-10-08 实跑 `npm test`，78/78 通过。零 npm 依赖。

## 格式与客户端要求

`.eprj3` 是原生桌面客户端文件夹工程：索引文件为 JSON，`sch/Schematic1/P1.esch2` 为原理图、`pcb/PCB1.epcb2` 为 PCB，另有 `.ecfg` 和 `.evar`。
必须解压完整工程目录后，用专业版离线／半离线桌面客户端打开索引文件。官方 eprj3 项目说明要求 V4.1+；自动化 CLI 要 V4.1.60+。
它不是标准版 JSON，也不是改名后的 KiCad 文件。
`.epro2` 是专业版 V3+ 使用的 ZIP 工程归档，通常需由真实客户端 `getProjectFile` 导出。当前没有实测的 `.epro2` 编码器，因此不伪造 ZIP 并改名。

用户采用网页端时，主交付为官方[「导入 KiCad」指引](https://prodocs.lceda.cn/cn/import-export/import-kicad/index.html)对应的 KiCad 5 工程 ZIP。本工程的 `.eprj3` 仅是附加桌面文件夹工程，不能交给网页端要求 `.epro` 的导入入口，也不构成网页导入实测。

官方 API 也明确支持 `SYS_FileManager.importProjectByProjectFile(file, 'KiCad', ..., {operation:'Offline Client Local Path', folderPath:...})`。这是 beta 导入接口。网络类、自定义规则、3D、SPICE 不由转换器迁移。

## 真正打开的验证边界

当前机器存在 KiCad 9.0.2 与 Chromium，但无 `easyeda-pro` 或 `lceda-pro` 客户端，也无已连接的官方桥接服务。
客户端与在线文档下载域名当时受到代理403／上游418、503限制。
因此能验证记录语法、字段格式、文档引用、每个符号脚网络、每个 PCB 焊盘位置和走线几何；不能宣称已在真实嘉立创桌面客户端打开或通过其 DRC。

原生工程文件生成无需登录；官方客户端 CLI 工作时需要实际安装并运行桌面客户端。

## 实测发现与外部修正

不修改官方工具源代码，`finalize-native.js` 对其输出做可审查的修正：

1. 添加官方结构要求的空 NET 记录和原理图 `.ecfg` 两条 TRACK 规则。
2. 统一各文档 `client` 为 `md5(owner_uuid)[:16]`，重排每文档逻辑票据。
3. 将 standalone NETLABEL 转为所属 WIRE 的 NET 属性，逐个检查标注点确实接在线段上。
4. 不连接标记的 X 使用非导电图形，消除转换器的悬空 lineGroup；原理图 NC 引脚网络依然为空。Rev A 为7脚，当前 Rev B 为9脚。
5. 修正 PCB 旋转。实跑 KiCad9 探针：`footprint at(10,10,90)`、`pad at(1,0,90)` 绝对焊盘坐标是 `(10,9)` mm。原转换器的 `angle=270` 会放到 `(10,11)`。修正为组件原角度，局部焊盘角度 `padAngle-footprintAngle`，逐个焊盘验算世界坐标。
6. PCB ATTR 使用父组件 id 加局部 id 的复合 id。
7. 保留源板参考标注位置、文字尺寸和是否隐藏。
8. 将 PCB 的精确封装文档嵌入原理图并绑定组件 Footprint，删除 FOOTPRINT 中无语义的 PART。
9. 对多层板启用对应内部铜层，并按真实导出样例写物理叠层。
10. 将椭圆钻槽由错误的 ROUND 记录纠正为 SLOT，保留槽长／孔径及槽相对焊盘方向；保留 KiCad roundrect 的实际圆角半径。
11. 为每个 symbol＋footprint 组合生成两者齐全的内嵌 DEVICE；原理图和 PCB 使用同一器件与 Unique ID，不依赖云端器件库。
12. PCB 元件添加与源 `Value` 一致的隐藏 `Name` 属性，避免共用同一符号／器件的电阻电容丢失各自实际数值；独立核对原理图与 PCB 全部位号和实际元件值。
13. 保留各铜区的优先级 `POUR.order`，依据源区的网络、层和精确边界独立匹配；写入源板一致的实心填充、最小厚度、孤岛删除及 `DIRECT` 焊盘连接规则。

物理叠层特别说明：当前 `layer_phys` 文档说 thickness 为0.1mm，真实官方 V4.1.36 导出模板则铜层1.379对应0.035mm、介质59.449对应1.510mm，即 mil；当前后处理采用真实导出值的单位。需在真实桌面客户端里确认并按实际厂商层压结构审核。不可把这里的字段级检查说成客户端叠层确认。

源板若有明确 stackup，则保留其铜／介质厚度；若只有板厚与铜层列表，输出的是每层35µm铜、总厚1.6mm的名义FR4叠层，不能将其描述为已选定的厂商介质结构。

规则单位也存在上游差异：当前官方 `t-rule-context.json` 描述 1长度单位=0.254mm，然而真实V4.1.36 PCB导出默认安全间距5.9843、最小线宽5、默认孔径规则12.0079/6.0039，其数值显然采用PCB mil口径；同一真实工程 SCH 规则值为mm。工程保留V4.1.36格式并采用对应真实PCB模板的mil编码；`native-design-rules.json` 写明预期mm数值及这一未解决差异。格式检查无法代替客户端规则显示确认。后处理脚本也提供显式 `internal10mil-current-schema` 选项，只有实际客户端确认对应格式口径后才应使用。

铜区最小填充厚度对应的 `POUR.width` 另有真实导出例外：官方转换器按 mm 写入，当前字段 schema 描述则按 mil。后处理保留该官方 mm 例外；`pourType.fineness` 和 PCB 铜区规则长度使用真实导出模板的 mil。当前源板所有铜区的间距、焊盘连接和热焊盘参数一致，故用四铜层的默认 `COPPER copperRegion` 规则表达，避免猜测未经验证的逐区规则选择器。非一致的逐区连接／间距／热焊盘参数、按面积阈值删除孤岛、hatch 填充及逐焊盘连接覆盖缺少已核验的映射时，适配器明确拒绝转换。当前 Rev B 不含这些特性。

## 验证工具

- `validate-native.js`：使用当前官方 `<DOCTYPE>_<TYPE>` schema，逐行校验外层记录。官方真实导出模板与字段类型差异单独列出，不修改 schema 以制造通过。
- `check-native-nets.js`：直接读取生成的原生符号、WIRE 与 NET 属性，重建逐物理脚网络并和源原理图比较。
- `check-native-pcb.js`：从原生 PCB 的组件／封装／PAD_NET 重建网络，与独立原始逐脚表比较；将所有直线轨迹的端点、宽度、网络、层别，所有过孔的位置、孔径、外径与所有铺铜边界／已填多边形逐一和 KiCad 源比较。
- `audit-native-project.js`：从设计清单与独立物理脚表动态取得元件／脚／网络数量，核对原生 SCH／PCB 实际元件值，汇总字段、网络、几何及库链接审计，并将报告绑定到最终源文件 SHA256。
- 官方 `easyeda-eprj3-skill/scripts/validate.js`：工程引用、逻辑票据、文档uuid、封装及器件链接、NET索引、线路组验证。

**2026-10-08 Rev A 历史原理图工具探针：**38组件、34网络、173物理脚（166已连接、7不连接）逐脚一致；所有1445行外层记录合法；字段验证没有未解释失败；官方结构验证0错误、0警告。这些数量不是当前 Rev B 的结果。

**2026-10-08 历史四层及槽孔工具探针：**90°旋转的0603与 SS12D10G4、7焊盘、4条手画轨迹、1过孔、4层铺铜及4个已填多边形转换前后一致；204行外层记录合法、字段无未解释失败、官方结构验证0错误／警告。该探针为工具校验样例，不是最终电机驱动板，也没有进行自动布线。

## 2026-10-09 Rev B 最终转换核验

入口为 `EasyEDA_Pro/DRV8701_DUAL_12V.eprj3`。聚合报告 `EasyEDA_Pro/native-final-audit.json` 绑定源 PCB SHA256 `daa3c5be68e8667a06f6da7ec5fd3c1238de758fb6982bcae6e130e6b8204989`，源原理图 SHA256 `da70605eba1826030f21ac655e2cb976c7ec27bc7cdd6379871e1fb34a657f04`；转换未改源文件。

- 45 元件的位号／实际值在原生原理图和 PCB 中均与 `design_netlist.json` 严格一致。
- 38 个命名网络、203 个唯一物理脚逐脚一致，其中9脚 NC；PCB 有211个焊盘实例，8个额外实例来自 MOS 同编号暴露焊盘。
- 592 线路段、151 过孔、12 铜区边界、12 已填多边形、4 板框边逐项一致；焊盘的绝对坐标、角度、尺寸、圆角、钻槽、镀孔、阻焊／锡膏扩展逐项一致。
- 39 × 60 mm 板框、四铜层和源板物理叠层一致：各铜层35 µm，含阻焊总厚1.6 mm。
- 4 个 F.Cu 相位铜区和 5 个 In2.Cu VM 铜区保留优先级2；3个 GND 铜区保留优先级0。全部 `DIRECT`、间距0.15 mm、最小填充厚度0.15 mm、删除所有未连接孤岛；源热焊盘间距0.25 mm、辐条宽度0.5 mm仍保存，但直连时不生效。
- 14 个配对器件、13 个封装全部内嵌，外部器件库依赖为0。
- 官方工程结构验证0错误、0警告。4096条记录外层全部合法，1877条直接满足当前字段 schema、164条来自可信官方真实导出模板；5273项已记录的模板／当前 schema 差异按具体字段保留解释，未映射类型0、未解释失败0。这些数量是文件格式审计统计，不是客户端 DRC。

最终代码采用设计清单动态统计，不再固定 Rev A 的38／34／173数量。新增 TPS25910 的标准 roundrect／rect 焊盘和符号引脚进入相同独立几何及逐脚检查，没有跳过新增 IC。

实际专业版桌面客户端打开、重新铺铜和 DRC 仍未实测；首次打开须确认1.6 mm、四铜层各35 µm、0.15 mm最小间距／线宽，以及源铜区优先级、直连、最小填充厚度和孤岛设置。保存的铜几何与源板一致不等于已经验证客户端重新填充行为。网页端主交付的实际 KiCad 5 检查另见 `KiCad_Import_5/validation/`。

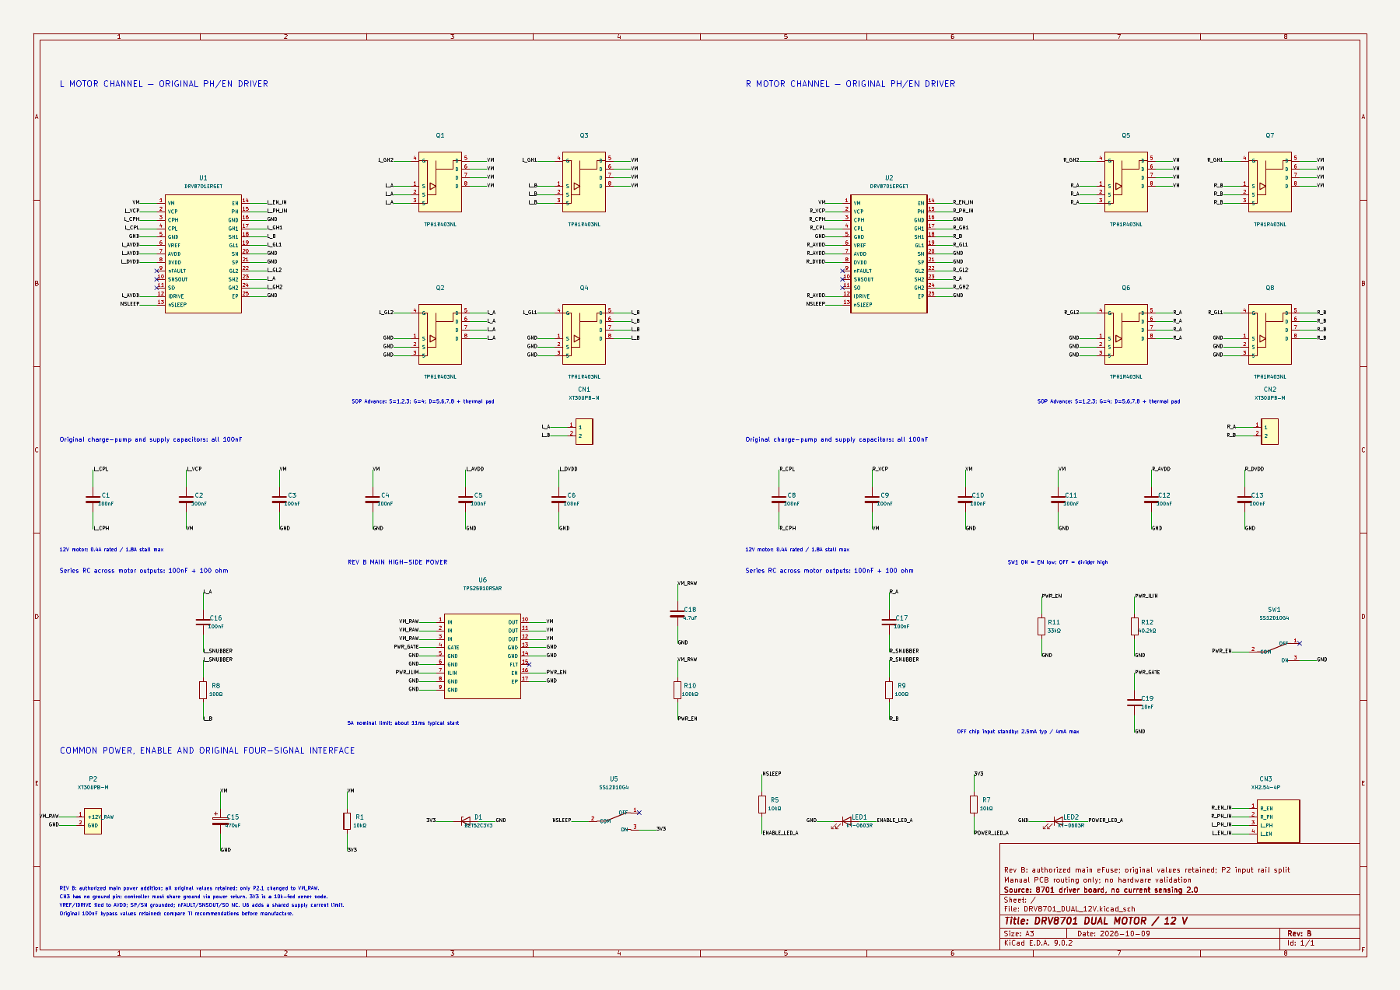
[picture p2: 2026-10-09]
hardware/drv8701-dual-12v/validation/rev_b_schematic_preview.png

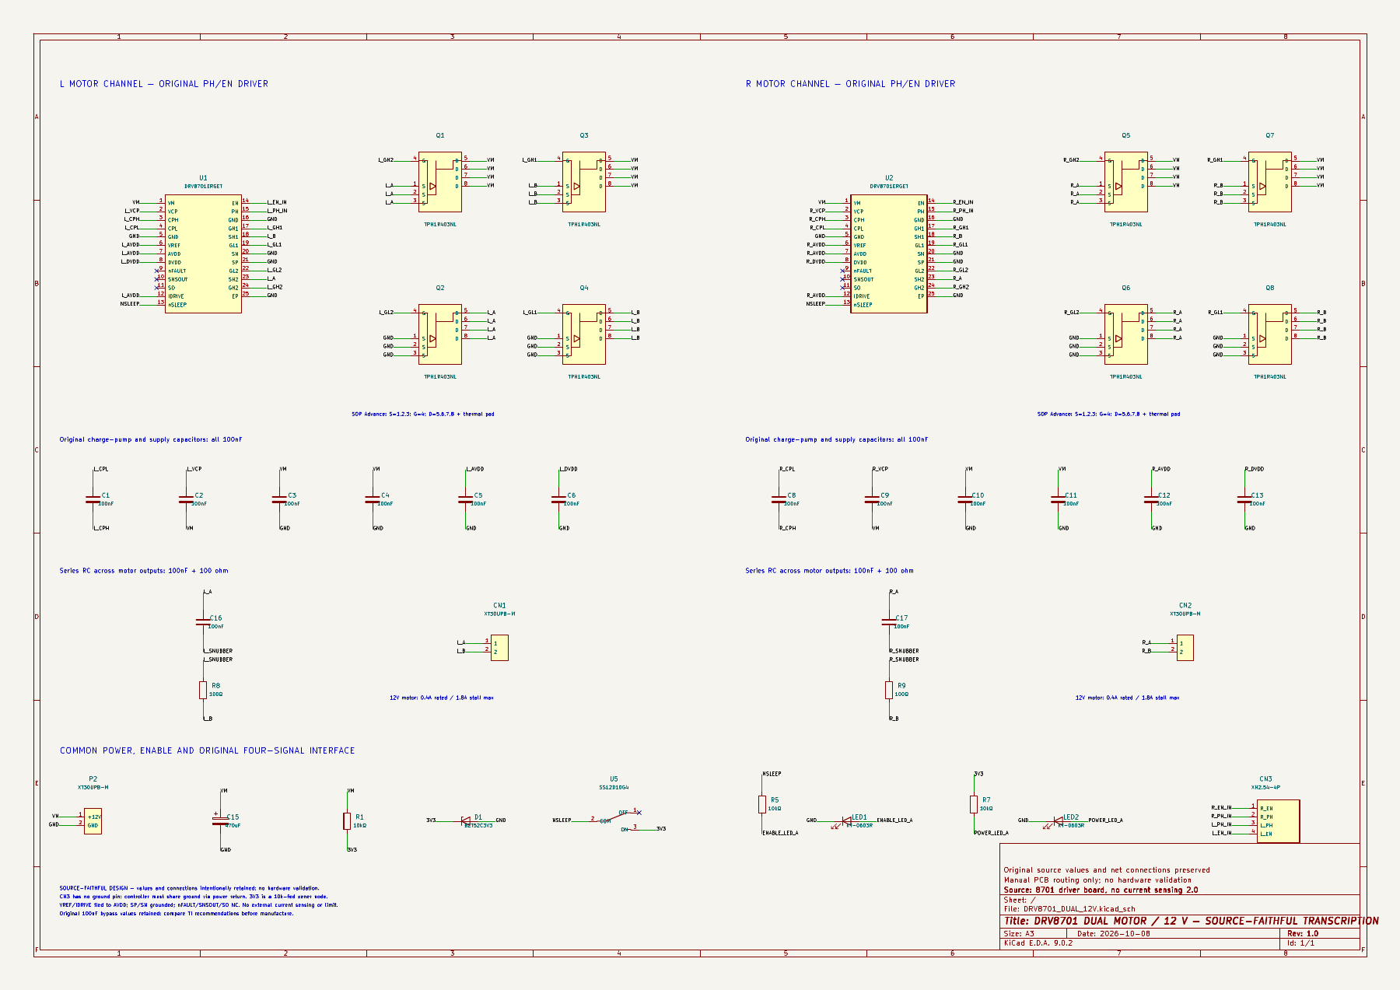
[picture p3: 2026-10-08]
hardware/drv8701-dual-12v/validation/schematic_preview.png

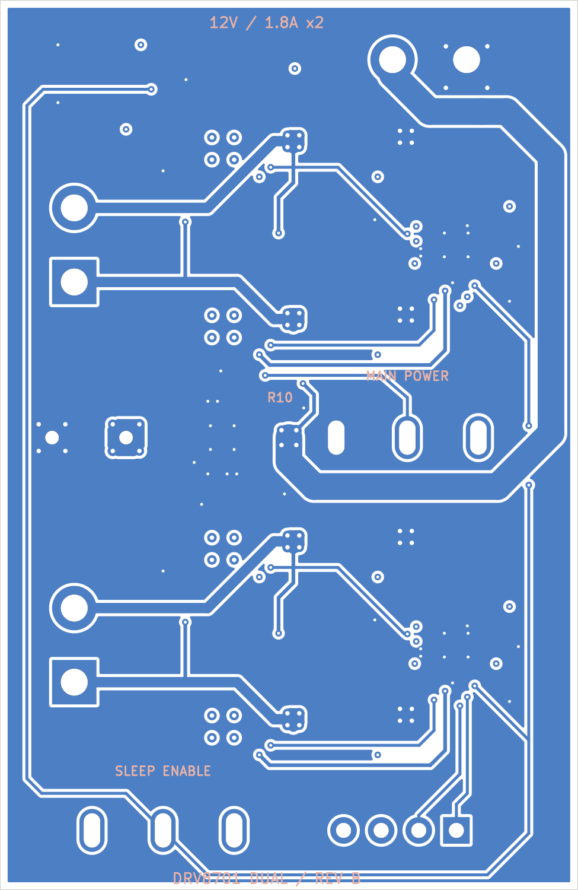
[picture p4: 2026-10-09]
hardware/drv8701-dual-12v/pcb_bottom.png

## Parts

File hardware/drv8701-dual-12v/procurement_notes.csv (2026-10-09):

References | Value | Quantity | Package | Selection requirements | Verification status
U1 U2 | DRV8701ERGET | 2 | VQFN RGE24 4x4mm 0.5mm pitch | Exposed GND pad must be soldered; TI RGE0024F land pattern | TI SLVSCX5B read
Q1 Q2 Q3 Q4 Q5 Q6 Q7 Q8 | TPH1R403NL | 8 | SOP Advance | Exact model; ordinary SOP Advance per manufacturer p8; 1-3 S / 4 G / 5-8 D / exposed D; do not substitute SOP Advance(N) | Toshiba Rev3.0.A electrical data and package outline read; recommended PCB land pattern not in PDF
C1 C2 C3 C4 C5 C6 C8 C9 C10 C11 C12 C13 C16 C17 | 100nF | 14 | 0603 | 25V or higher X7R ceramic; original capacitance preserved | Package verified; exact purchased part DC-bias curve must be checked
C15 | 470uF | 1 | Radial diameter 10mm pitch 5mm | 25V low-ESR electrolytic; maximum body diameter 10mm; verify ripple-current rating | Value preserved; package envelope selected
R1 R5 R7 | 10kΩ | 3 | 0603 | 1% or 5%; rated power at least 0.1W | Original resistance preserved
R8 R9 | 100Ω | 2 | 1210 | Rated power at least 0.5W; for EN PWM <=20kHz at 12V | Original resistance preserved; RC heat estimate documented
D1 | BZT52C3V3 | 1 | SOD123 | Exact 3.3V Zener model; pin1 K / pin2 A; low-current Zener voltage requires measurement | Original value and network preserved
LED1 LED2 | KT-0603R | 2 | 0603 | Red LED; pin1 K / pin2 A | Original model and network preserved
CN1 CN2 P2 | XT30UPB-M | 3 | Through-hole pitch 5mm | Check board-mount male part; source pin1 positive at +2.5mm and pin2 negative at -2.5mm; motor polarity is phase-dependent | Source numbering intentionally differs from some library conventions
CN3 | XH2.54-4P | 1 | Through-hole pitch 2.54mm | Buy 2.54mm-pitch part matching footprint; four signals only; controller needs separate common GND | Do not substitute JST 2.50mm part without footprint check
U5 SW1 | SS12D10G4 | 2 | Through-hole slide switch | Body 12.7x6.7mm; pin pitch 4.8mm; user pin 1.3x0.8mm fits 2.3x1.1mm slots; no mounting holes | Exact footprint and user dimensions cross-checked; U5 controls nSLEEP and SW1 controls active-low TPS25910 EN
U6 | TPS25910RSAR | 1 | VQFN RSA16 4x4mm 0.65mm pitch | Exact RSA package; 17th exposed pad to GND; solder EP and follow TI RSA0016B land/stencil pattern; do not substitute a different package | TI SLUSAR6D and TPS25910EVM SLVU760A read; 17-pad footprint independently checked; board thermal performance untested
R10 R11 | 100kΩ / 33kΩ | 2 | 0603 | R10=100kΩ; R11=33kΩ; 1%; at least 0.1W; TPS25910 EN divider | Rev B added values checked against control schematic
R12 | 40.2kΩ | 1 | 0603 | 1%; at least 0.1W; TPS25910 ILIM resistor | TI gives 4.5A minimum / 5A typical / 5.5A maximum limit for 40.2kΩ; not a per-motor current sensor
C18 | 4.7uF | 1 | 0805 | 50V X7R; select exact part with effective capacitance >=1uF at 12V after DC bias and tolerance; this is an engineering procurement target and not a TI hard minimum | No exact purchased part selected; manufacturer DC-bias curve not yet verified
C19 | 10nF | 1 | 0603 | 50V C0G; +/-5%; TPS25910 GATE ramp capacitor | TI gate-charge model checked; startup timing and thermal/SOA behavior require board measurement

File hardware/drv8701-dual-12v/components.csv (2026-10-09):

Reference | Value | Footprint | Quantity | PCB side | Source fidelity | Rating / tolerance
U1 | DRV8701ERGET | DRV8701_Custom:DRV8701_RGE24 | 1 | Front | Original value and connectivity
Q1 | TPH1R403NL | DRV8701_Custom:TPH1R403NL_SOPAdvance | 1 | Front | Original value and connectivity
Q2 | TPH1R403NL | DRV8701_Custom:TPH1R403NL_SOPAdvance | 1 | Front | Original value and connectivity
Q3 | TPH1R403NL | DRV8701_Custom:TPH1R403NL_SOPAdvance | 1 | Front | Original value and connectivity
Q4 | TPH1R403NL | DRV8701_Custom:TPH1R403NL_SOPAdvance | 1 | Front | Original value and connectivity
C1 | 100nF | DRV8701_Custom:C_0603_1608Metric | 1 | Front | Original value and connectivity
C2 | 100nF | DRV8701_Custom:C_0603_1608Metric | 1 | Front | Original value and connectivity
C3 | 100nF | DRV8701_Custom:C_0603_1608Metric | 1 | Front | Original value and connectivity
C4 | 100nF | DRV8701_Custom:C_0603_1608Metric | 1 | Front | Original value and connectivity
C5 | 100nF | DRV8701_Custom:C_0603_1608Metric | 1 | Front | Original value and connectivity
C6 | 100nF | DRV8701_Custom:C_0603_1608Metric | 1 | Front | Original value and connectivity
C16 | 100nF | DRV8701_Custom:C_0603_1608Metric | 1 | Front | Original value and connectivity
R8 | 100Ω | DRV8701_Custom:R_1210_3225Metric | 1 | Front | Original value and connectivity
CN1 | XT30UPB-M | DRV8701_Custom:AMASS_XT30UPB_M_SourceNumbering | 1 | Front | Original value and connectivity
U2 | DRV8701ERGET | DRV8701_Custom:DRV8701_RGE24 | 1 | Front | Original value and connectivity
Q5 | TPH1R403NL | DRV8701_Custom:TPH1R403NL_SOPAdvance | 1 | Front | Original value and connectivity
Q6 | TPH1R403NL | DRV8701_Custom:TPH1R403NL_SOPAdvance | 1 | Front | Original value and connectivity
Q7 | TPH1R403NL | DRV8701_Custom:TPH1R403NL_SOPAdvance | 1 | Front | Original value and connectivity
Q8 | TPH1R403NL | DRV8701_Custom:TPH1R403NL_SOPAdvance | 1 | Front | Original value and connectivity
C8 | 100nF | DRV8701_Custom:C_0603_1608Metric | 1 | Front | Original value and connectivity
C9 | 100nF | DRV8701_Custom:C_0603_1608Metric | 1 | Front | Original value and connectivity
C10 | 100nF | DRV8701_Custom:C_0603_1608Metric | 1 | Front | Original value and connectivity
C11 | 100nF | DRV8701_Custom:C_0603_1608Metric | 1 | Front | Original value and connectivity
C12 | 100nF | DRV8701_Custom:C_0603_1608Metric | 1 | Front | Original value and connectivity
C13 | 100nF | DRV8701_Custom:C_0603_1608Metric | 1 | Front | Original value and connectivity
C17 | 100nF | DRV8701_Custom:C_0603_1608Metric | 1 | Front | Original value and connectivity
R9 | 100Ω | DRV8701_Custom:R_1210_3225Metric | 1 | Front | Original value and connectivity
CN2 | XT30UPB-M | DRV8701_Custom:AMASS_XT30UPB_M_SourceNumbering | 1 | Front | Original value and connectivity
U6 | TPS25910RSAR | DRV8701_Custom:TPS25910_RSA16 | 1 | Front | Authorized Rev B addition
C18 | 4.7uF | DRV8701_Custom:C_0805_2012Metric | 1 | Front | Authorized Rev B addition | 50V X7R 0805; verify exact selected part effective capacitance >=1uF at 12V from manufacturer DC-bias curve
R10 | 100kΩ | DRV8701_Custom:R_0603_1608Metric | 1 | Front | Authorized Rev B addition | 1%
R11 | 33kΩ | DRV8701_Custom:R_0603_1608Metric | 1 | Front | Authorized Rev B addition | 1%
R12 | 40.2kΩ | DRV8701_Custom:R_0603_1608Metric | 1 | Front | Authorized Rev B addition | 1%
C19 | 10nF | DRV8701_Custom:C_0603_1608Metric | 1 | Front | Authorized Rev B addition | 50V C0G
SW1 | SS12D10G4 | DRV8701_Custom:SS12D10G4 | 1 | Front | Authorized Rev B addition
P2 | XT30UPB-M | DRV8701_Custom:AMASS_XT30UPB_M_SourceNumbering | 1 | Front | Original value; authorized P2.1 net split
C15 | 470uF | DRV8701_Custom:CP_Radial_D10.0mm_P5.00mm | 1 | Front | Original value and connectivity
R1 | 10kΩ | DRV8701_Custom:R_0603_1608Metric | 1 | Front | Original value and connectivity
D1 | BZT52C3V3 | DRV8701_Custom:D_SOD123 | 1 | Front | Original value and connectivity
U5 | SS12D10G4 | DRV8701_Custom:SS12D10G4 | 1 | Front | Original value and connectivity
R5 | 10kΩ | DRV8701_Custom:R_0603_1608Metric | 1 | Front | Original value and connectivity
LED1 | KT-0603R | DRV8701_Custom:LED_0603_1608Metric | 1 | Front | Original value and connectivity
R7 | 10kΩ | DRV8701_Custom:R_0603_1608Metric | 1 | Front | Original value and connectivity
LED2 | KT-0603R | DRV8701_Custom:LED_0603_1608Metric | 1 | Front | Original value and connectivity
CN3 | XH2.54-4P | DRV8701_Custom:XH2.54_1x04_Vertical | 1 | Front | Original value and connectivity

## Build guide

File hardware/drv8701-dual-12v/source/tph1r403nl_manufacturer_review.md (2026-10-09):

# TPH1R403NL 原厂手册核对

读取日期：2026-10-09。本记录核对MOS器件资料与封装，本次资料核对没有改变原图MOS连接或取值。Rev B的布局重排及授权主电源新增另见工程README；不把资料核对范围表述为整块PCB从Rev A起未变。

- Toshiba官网URL成功下载并可读取： https://toshiba.semicon-storage.com/info/TPH1R403NL_datasheet_en_20191030.pdf?did=14296&prodName=TPH1R403NL 。
- 尽管URL文件名含20191030，服务器目前实际返回 **2026-04-14 Rev.3.0.A、10页** 的官方 TPH1R403NL 手册；依据PDF内容记录版本。
- 交付文件：`Toshiba_TPH1R403NL_Rev3_0_A.pdf`。SHA256 `12a06e5d86ab4f4fd7d9dc543e2c7d85796f29c18ecd32b010ac4c99267ede17`。
- LCSC已知精确镜像仍HTTP403： https://atta.szlcsc.com/upload/public/pdf/source/20220830/C277A7BCA37DB7348B2C95BA2E6DA6BE.pdf 。TLS验证保持开启。

## 核对结论

|项目|原厂数据|页码|
|---|---|---|
|引脚|1/2/3 Source；4 Gate；5/6/7/8 Drain，裸露大金属亦属Drain|p1内部电路、p8底视机械图|
|VDS绝对最大|30V|p2|
|VGS绝对最大|±20V|p2|
|RDS(on)|VGS=10V、ID=30A：典型1.2mΩ、最大1.4mΩ；VGS=4.5V、ID=30A：典型1.7mΩ、最大2.1mΩ|p3|
|Qg|典型46nC（VGS10V），典型20nC（VGS4.5V）；VDD≈15V、ID60A，无最大值保证|p3|
|Qgd|典型4.3nC；VDD≈15V、VGS10V、ID60A|p3|
|SOP Advance|Toshiba2-5Q1S：body5±0.2×5±0.2mm；lead span6±0.3mm；pitch1.27mm；lead width0.4±0.1mm；height0.95±0.05mm|p8|
|裸露Drain金属|4.25±0.2×3.5±0.2mm|p8|

当前PCB所用SOP Advance库为5×5mm、1.27mm pitch、source1–3/gate4/drain5–8，裸露drain pad4.25×3.5mm，关键尺寸与p8原厂 **封装金属图** 相符。PCB外围引脚铜焊盘0.5×1.2mm、中心±2.77mm为设计焊盘，不应将其声称为本手册给出的推荐land pattern；此PDF没有提供推荐PCB铜焊盘图。手焊toes与裸露底部焊接仍须实际工艺验证。

新版手册也列出SOP Advance(N)/2-5W1A（p9），其body、height和裸露金属不同；现有库针对p8普通SOP Advance。采购时必须匹配实际供货封装，不能凭“TPH1R403NL”型号忽略封装版本。

原图IDRIVE直连AVDD严格保留，TI定义25mA源/50mA灌且关闭高侧VDS OCP。以Toshiba典型Qg=46nC做一阶估算，充/放电约1.84µs/0.92µs，均小于TI tDRIVE≈2.5µs；Qgd/IDRIVE对应Miller阶段约172ns/86ns。该比较支持原驱动设置可用的典型参数初筛，**不代表最大公差保证或实际VGS波形测试**，尤其不消除原图小电荷泵/去耦值的验证需求。

本记录仅完成官方资料与封装的静态核对，不授权改原值。实际通电、堵转／温升／EMI和真实嘉立创EDA客户端测试仍未进行。Toshiba精确原厂PDF已读取；“官方推荐PCB焊盘图／实板工艺均已验证”仍不能声称。

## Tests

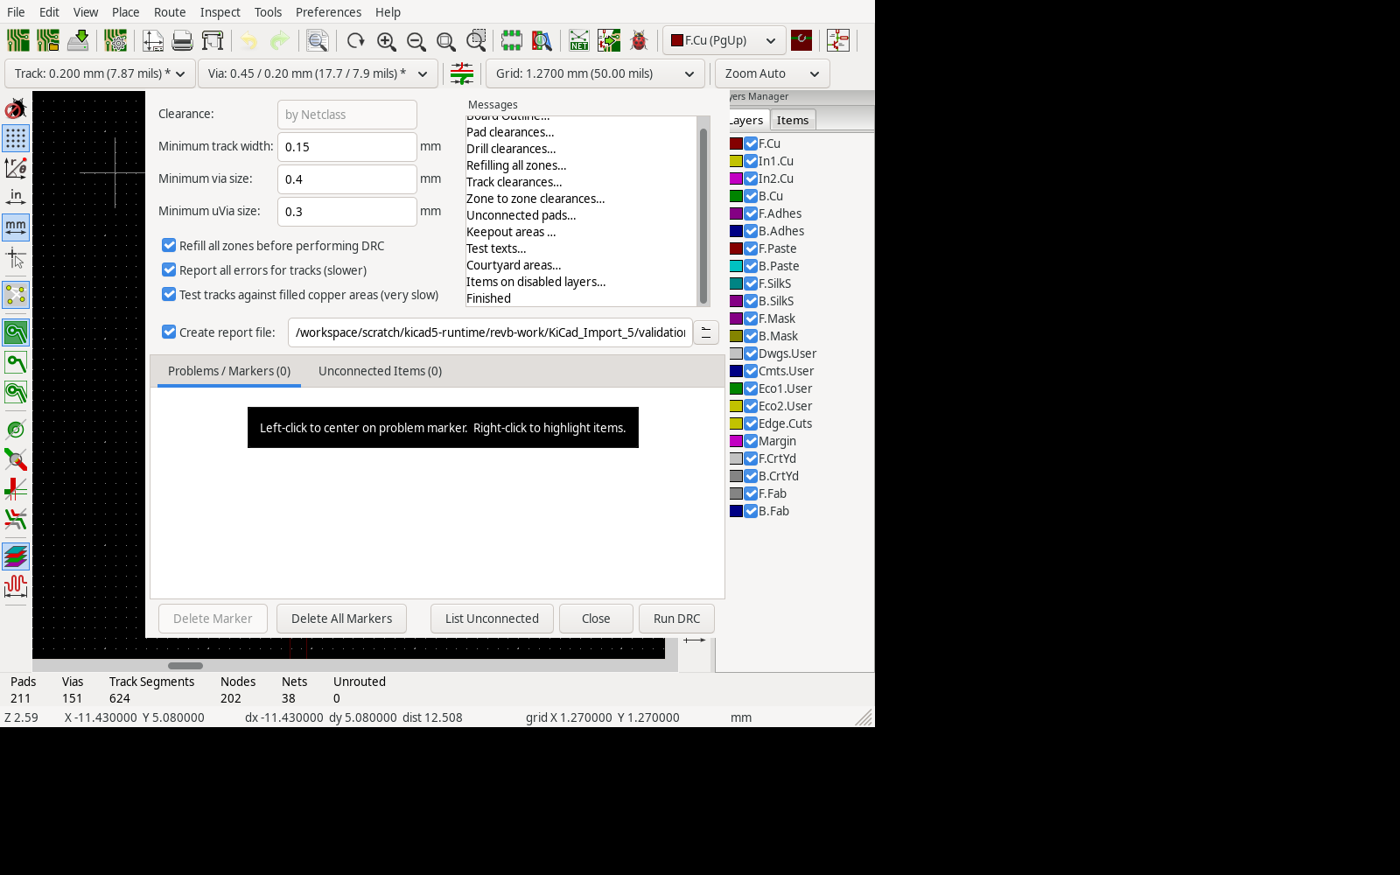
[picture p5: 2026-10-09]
hardware/drv8701-dual-12v/KiCad_Import_5/validation/actual5_drc_run.png

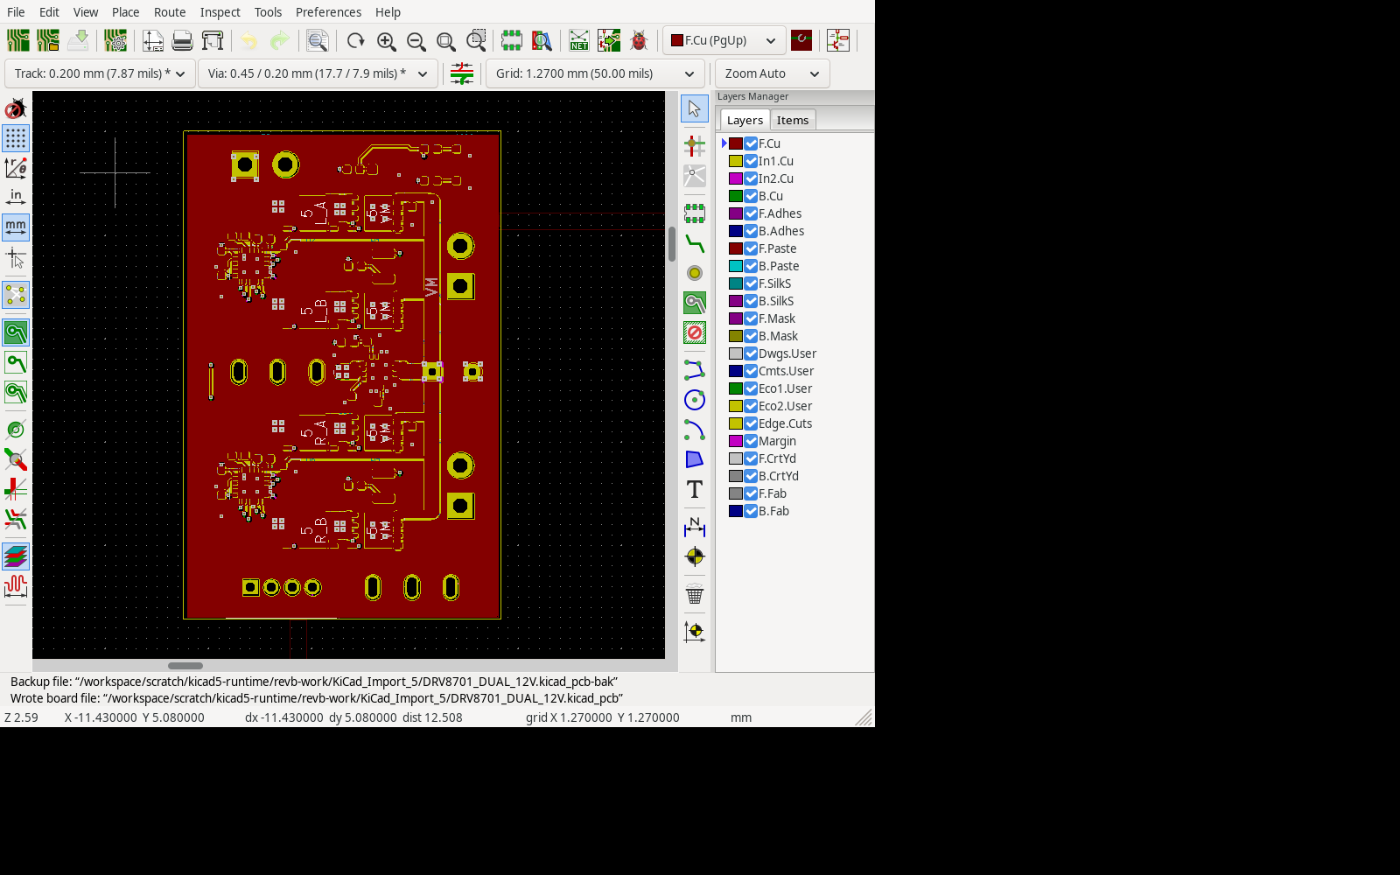
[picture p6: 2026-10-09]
hardware/drv8701-dual-12v/KiCad_Import_5/validation/actual5_pcb_open.png

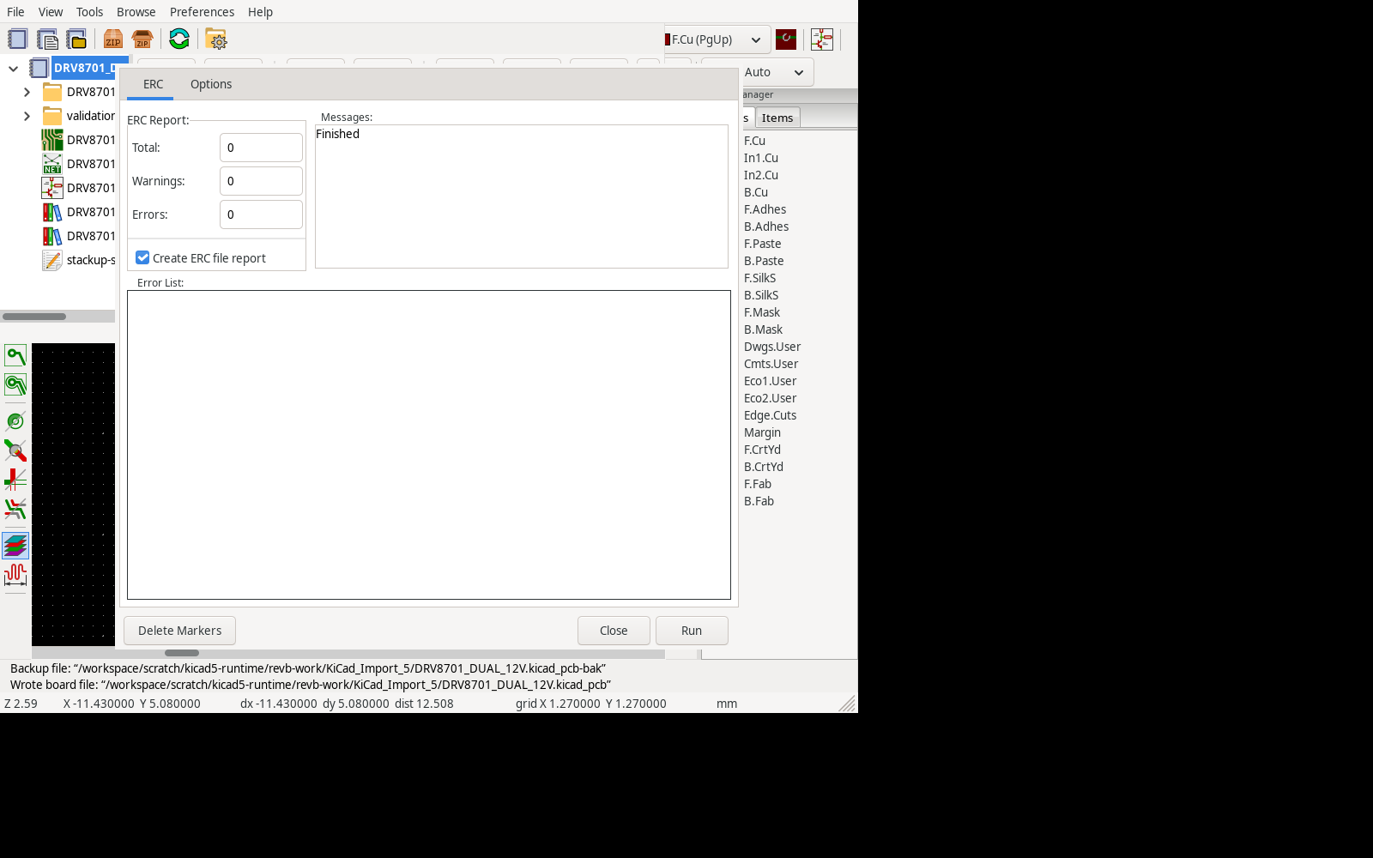
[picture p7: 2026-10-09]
hardware/drv8701-dual-12v/KiCad_Import_5/validation/actual5_erc_run.png

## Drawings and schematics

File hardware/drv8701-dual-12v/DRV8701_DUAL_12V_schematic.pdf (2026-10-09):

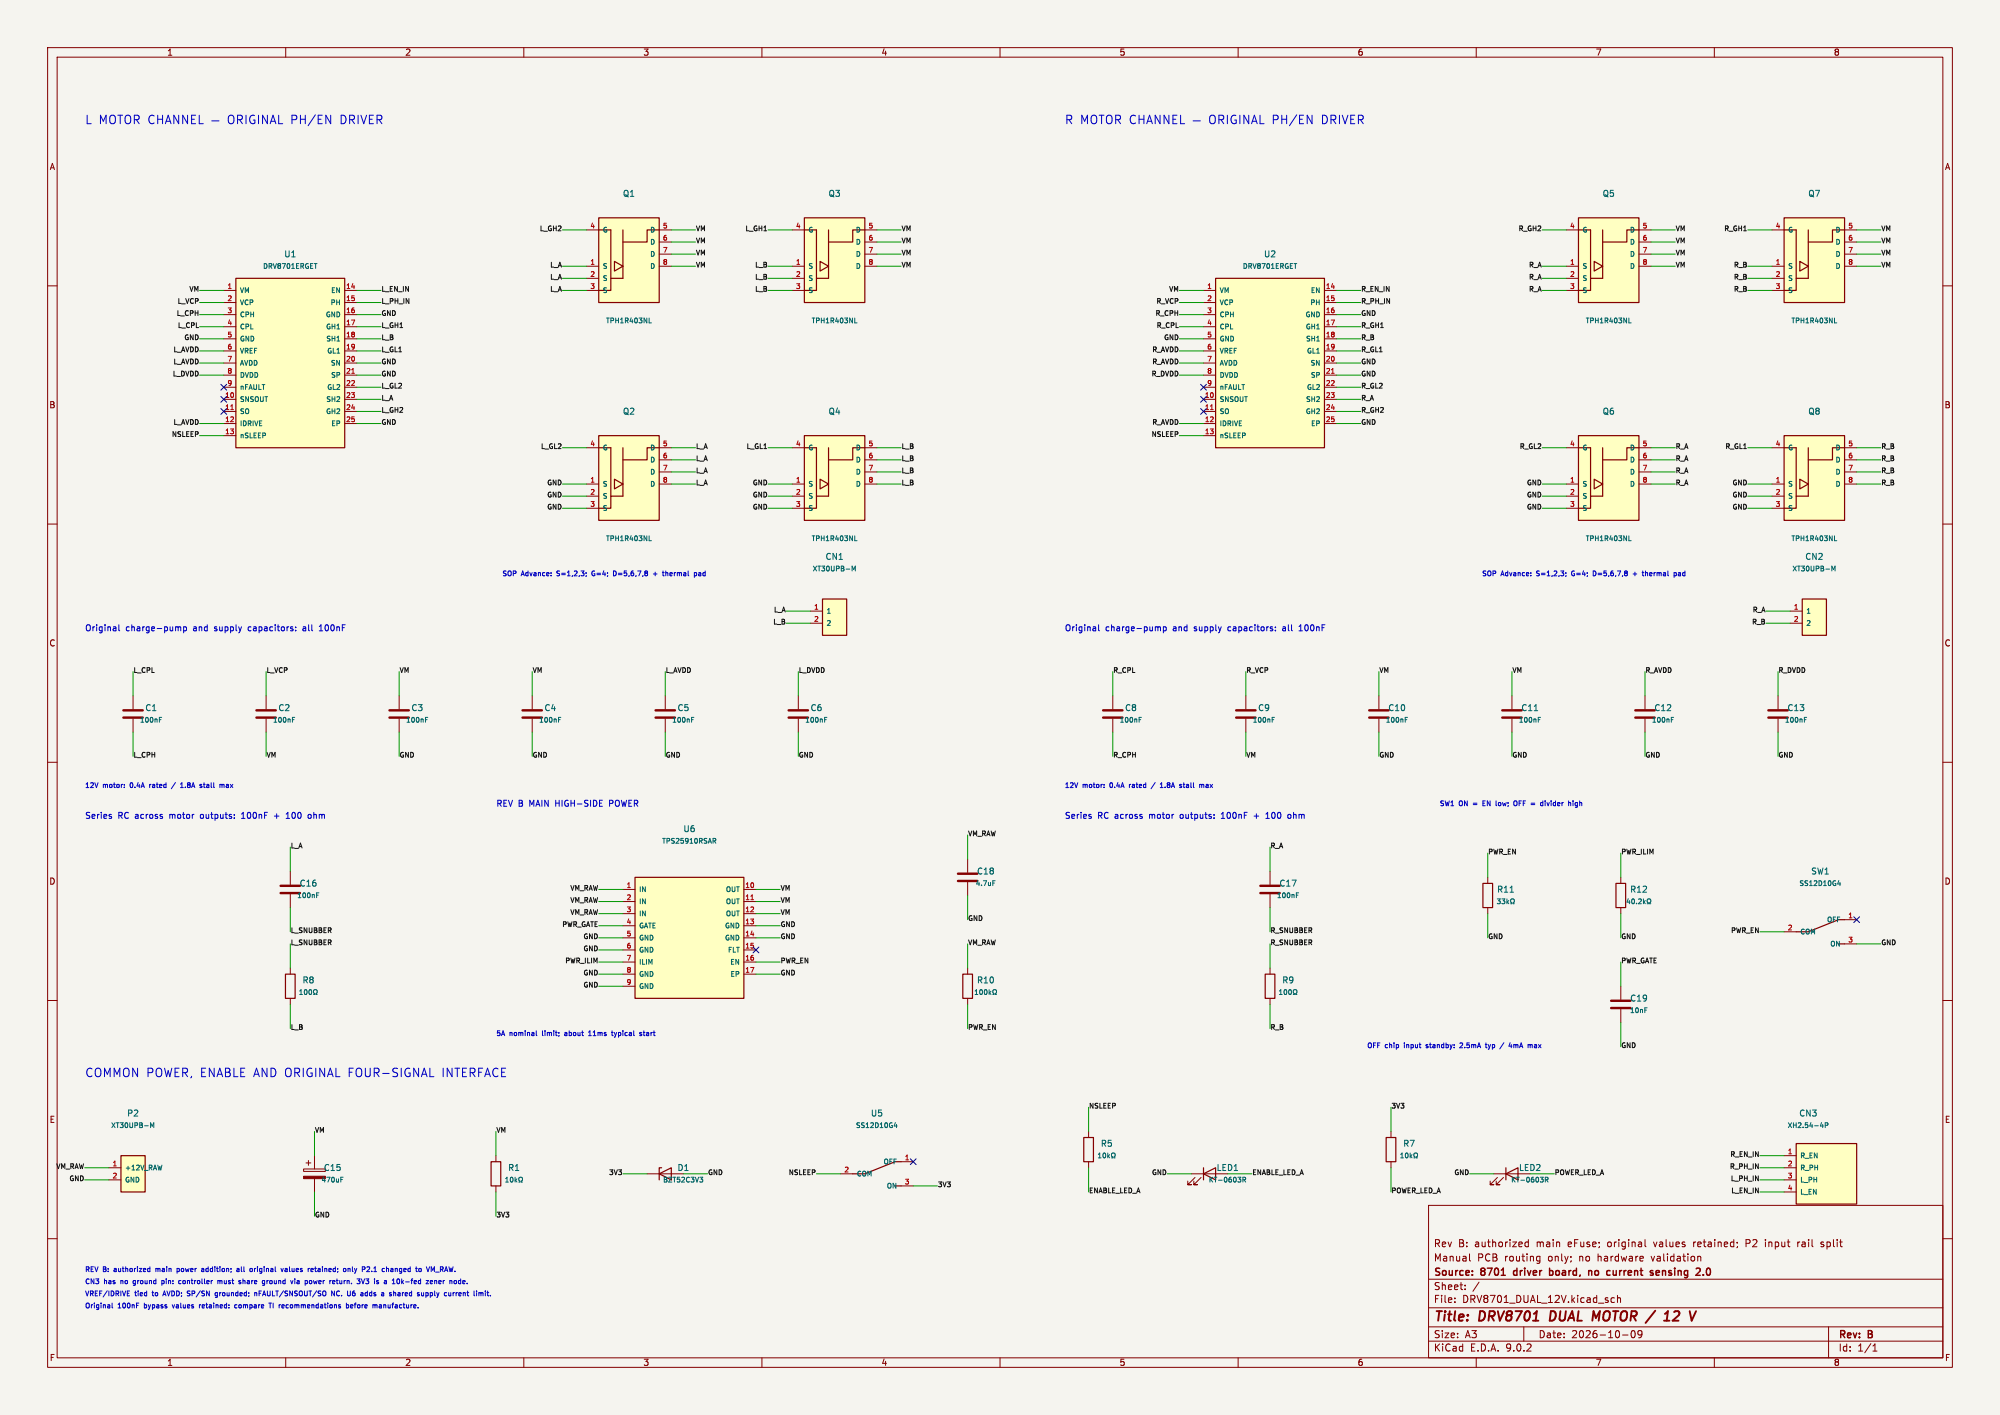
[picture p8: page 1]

L MOTOR CHANNEL þÿ ORIGINAL PH/EN DRIVER

R MOTOR CHANNEL þÿ ORIGINAL PH/EN DRIVER

VM 1 VCP 2 CPH 3 CPL 4 GND 5 VREF 6 AVDD 7 DVDD 8

REV B MAIN HIGH-SIDE POWER

IN 3 GATE 4 GND 5 GND 6

COMMON POWER, ENABLE AND ORIGINAL FOUR-SIGNAL INTERFACE

Id: 1/1 Title: DRV8701 DUAL MOTOR / 12 V

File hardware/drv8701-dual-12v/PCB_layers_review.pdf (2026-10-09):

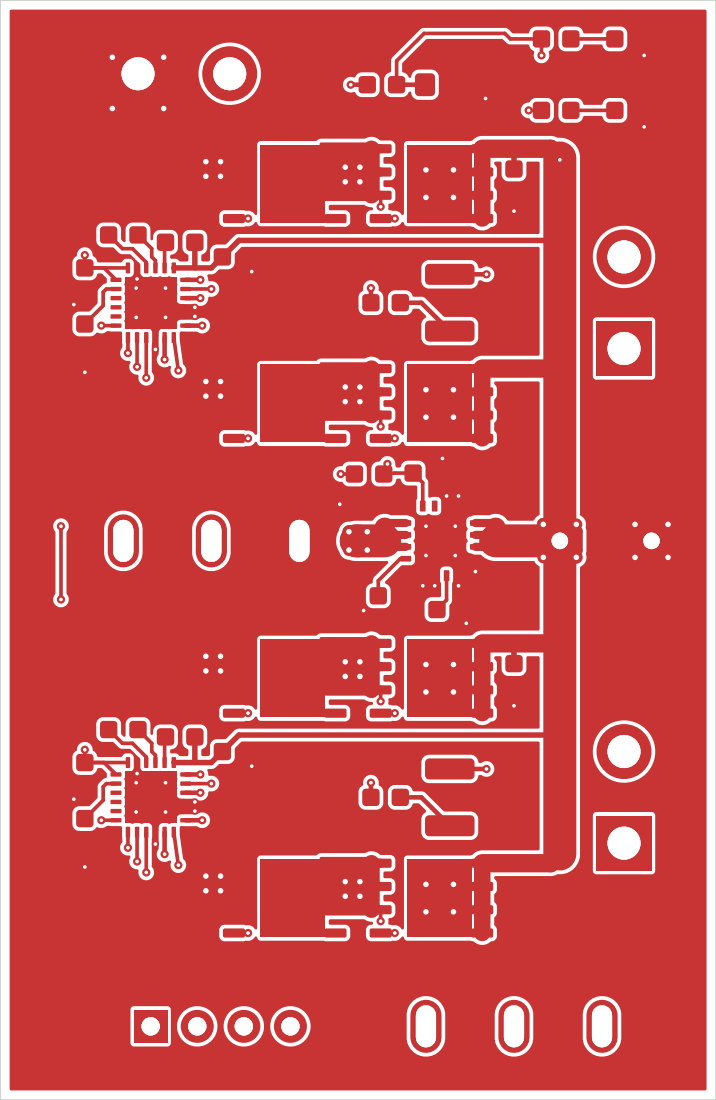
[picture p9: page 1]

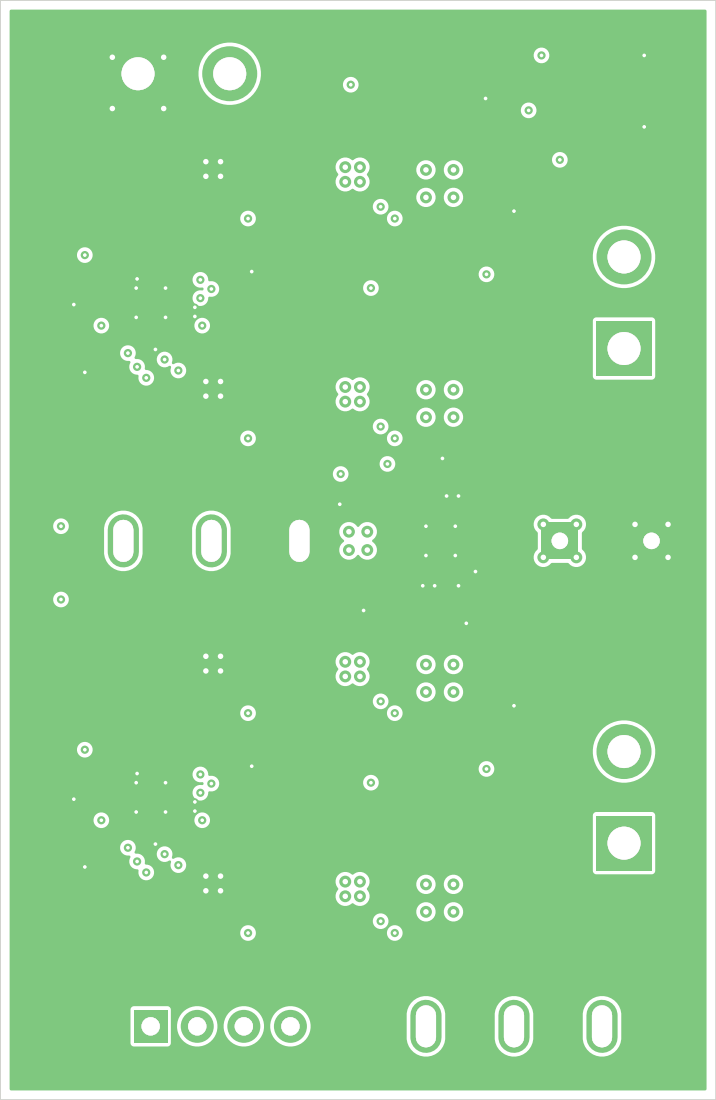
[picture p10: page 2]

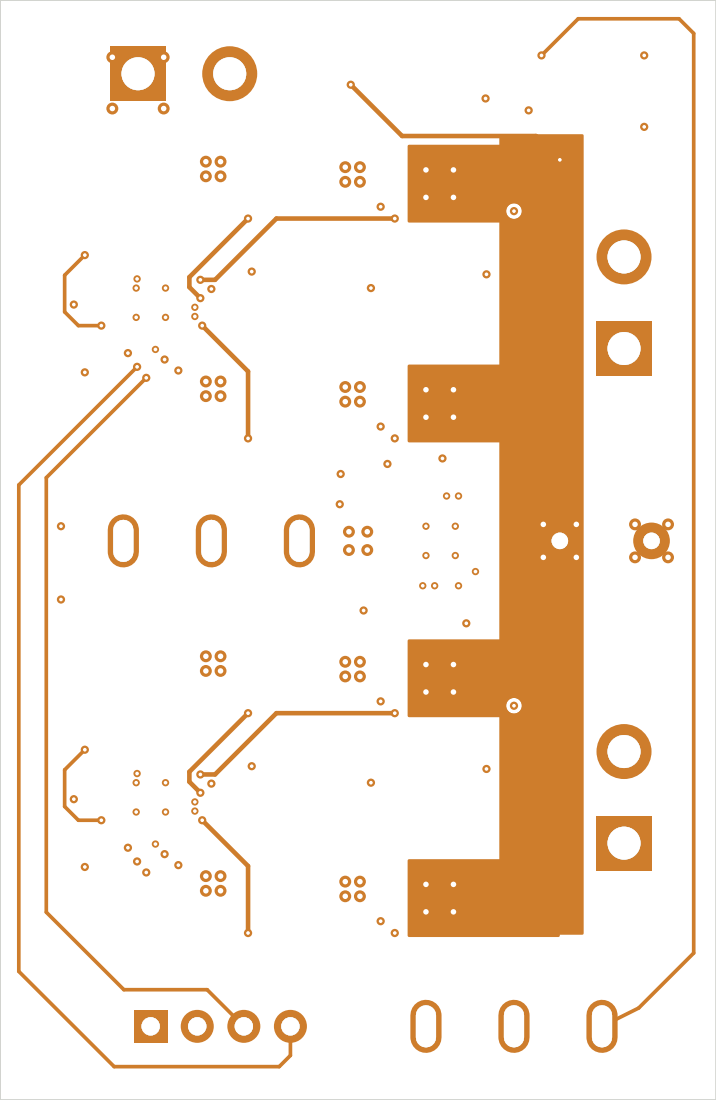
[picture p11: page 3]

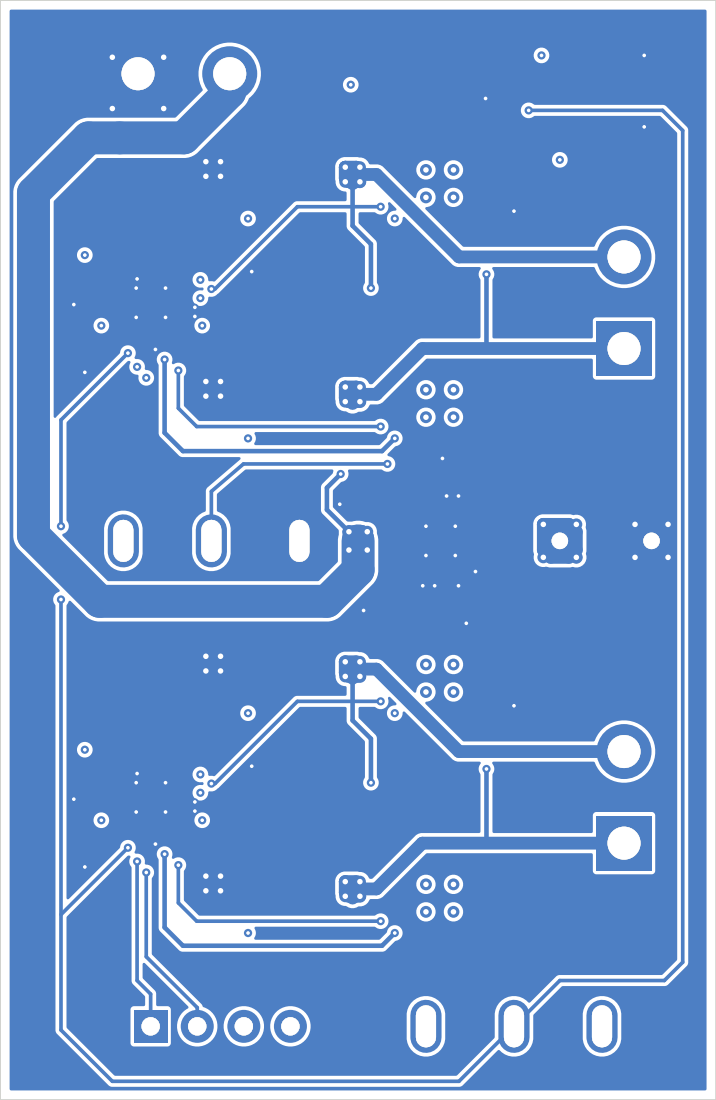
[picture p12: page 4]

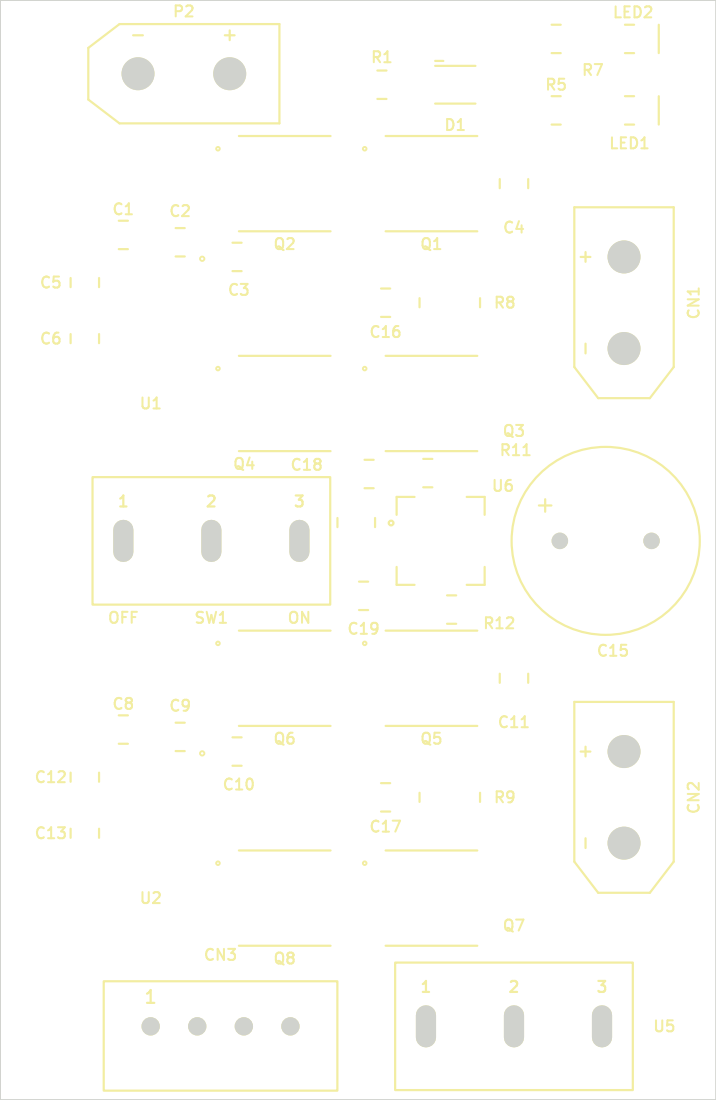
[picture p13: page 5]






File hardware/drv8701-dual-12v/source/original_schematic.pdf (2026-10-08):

# 左电机驱动电路

电机接口 | 电源接口

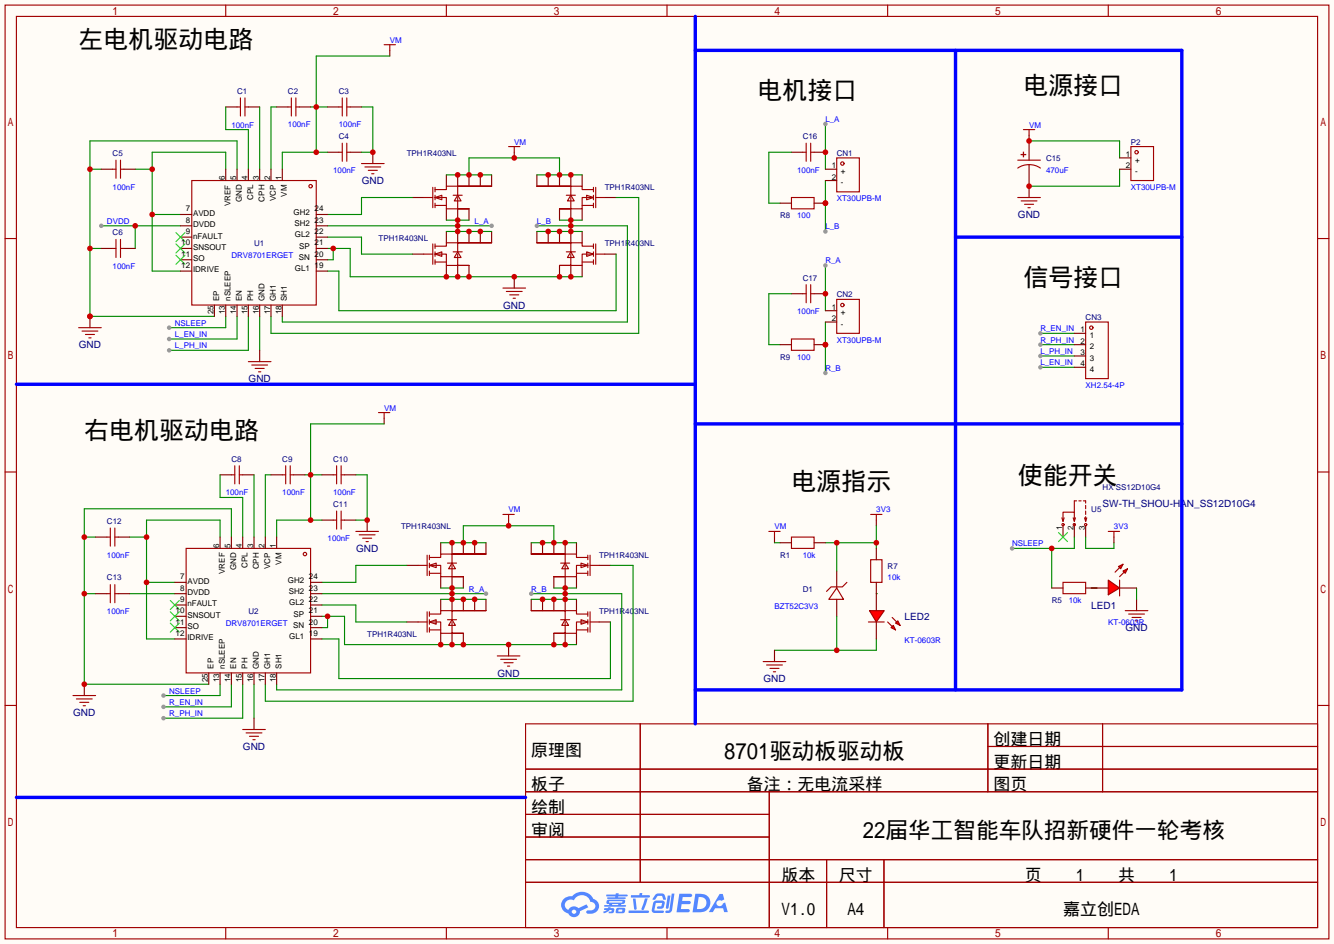
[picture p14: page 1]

原理图 | 8701驱动板驱动板 | 创建日期

更新日期

板子 | 备注：无电流采样 | 图页
绘制 | | 22届华工智能车队招新硬件一轮考核
审阅

V1.0 | A4 | 嘉立创EDA

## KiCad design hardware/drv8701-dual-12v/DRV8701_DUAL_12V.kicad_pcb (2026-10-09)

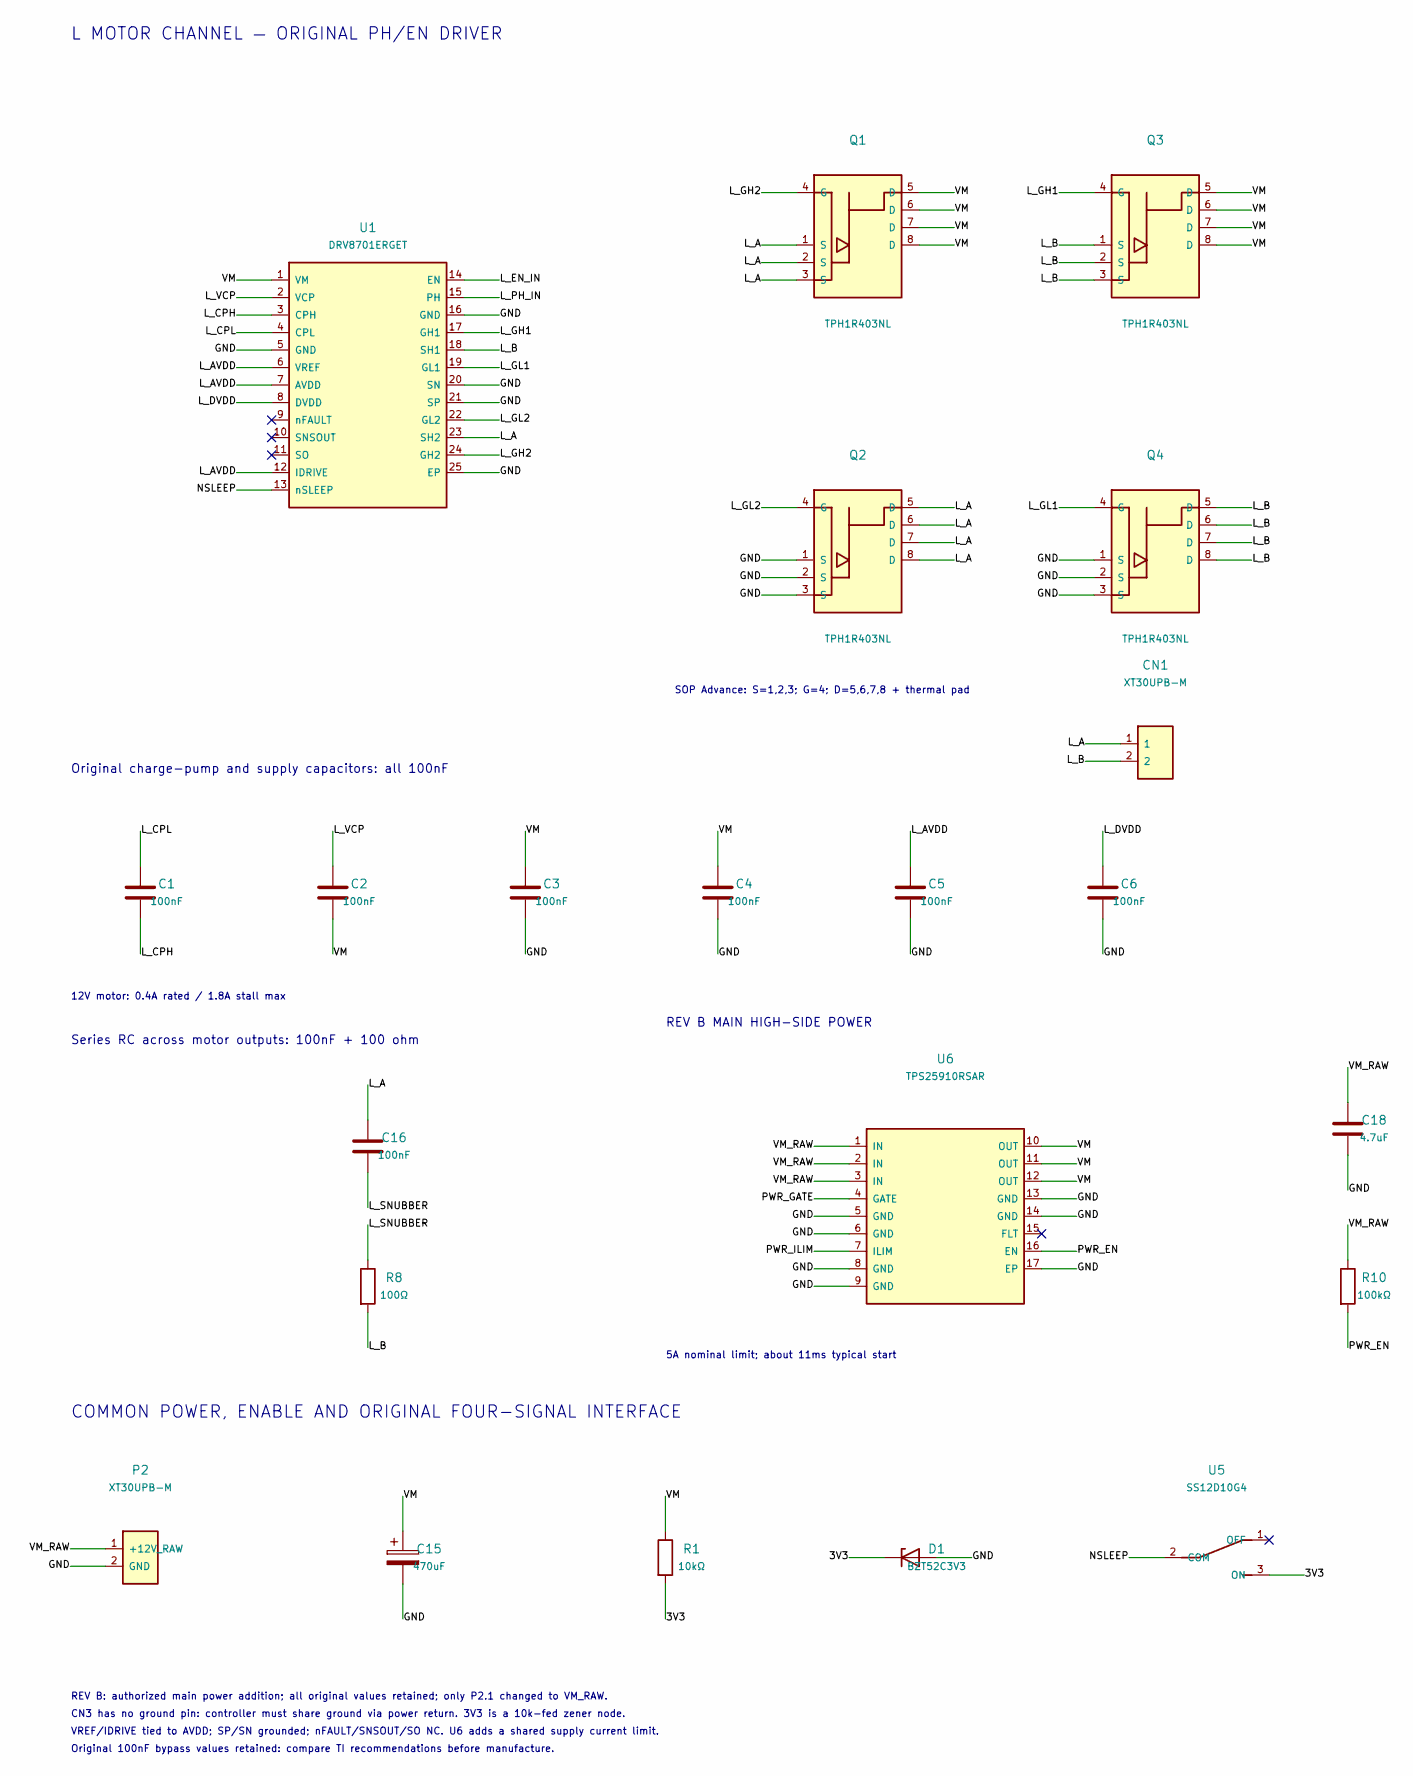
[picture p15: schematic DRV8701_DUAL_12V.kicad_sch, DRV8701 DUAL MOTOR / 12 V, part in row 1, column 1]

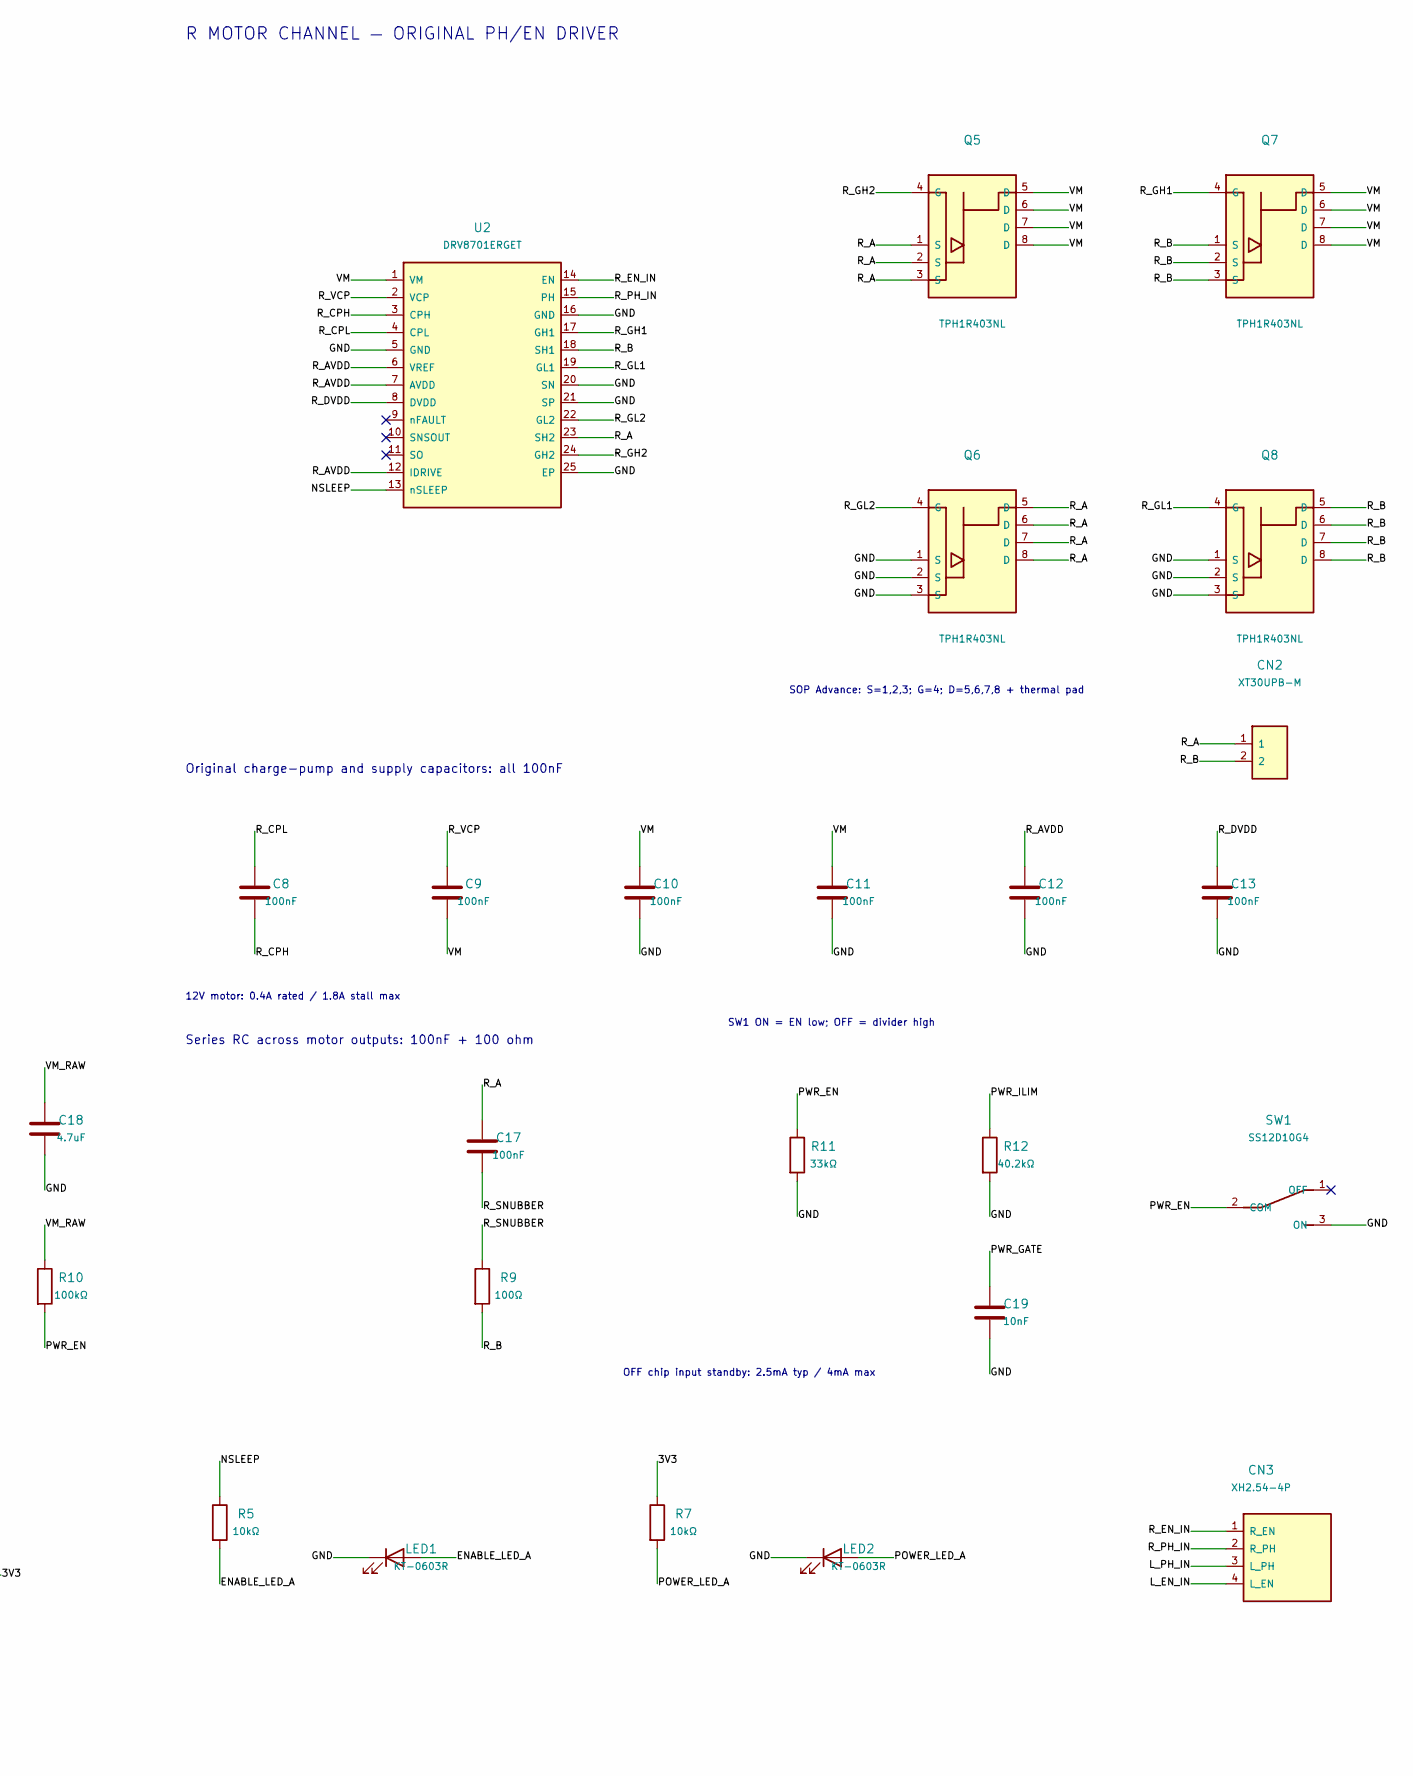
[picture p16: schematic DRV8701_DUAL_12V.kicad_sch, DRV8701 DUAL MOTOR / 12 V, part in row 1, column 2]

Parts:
C1, C2, C3, C4, C5, C6, C8, C9, C10, C11, C12, C13, C16, C17: 100nF; C_0603_1608Metric
C15: 470uF; CP_Radial_D10.0mm_P5.00mm
C18: 4.7uF; C_0805_2012Metric
C19: 10nF; C_0603_1608Metric
CN1, CN2: XT30UPB-M; AMASS_XT30UPB_M_SourceNumbering
CN3: XH2.54-4P; XH2.54_1x04_Vertical
D1: BZT52C3V3; D_SOD123
LED1, LED2: KT-0603R; LED_0603_1608Metric
P2: XT30UPB-M; AMASS_XT30UPB_M_SourceNumbering
Q1, Q2, Q3, Q4, Q5, Q6, Q7, Q8: TPH1R403NL; TPH1R403NL_SOPAdvance
R1, R5, R7: 10kΩ; R_0603_1608Metric
R8, R9: 100Ω; R_1210_3225Metric
R10: 100kΩ; R_0603_1608Metric
R11: 33kΩ; R_0603_1608Metric
R12: 40.2kΩ; R_0603_1608Metric
SW1: SS12D10G4
U1, U2: DRV8701ERGET; DRV8701_RGE24
U5: SS12D10G4
U6: TPS25910RSAR; TPS25910_RSA16

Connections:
3V3: D1.1 (K), R1.2, R7.1, U5.3 (ON)
ENABLE_LED_A: LED1.2 (A), R5.2
GND: C3.2, C4.2, C5.2, C6.2, C10.2, C11.2, C12.2, C13.2, C15.2, C18.2, C19.2, D1.2 (A), LED1.1 (K), LED2.1 (K), P2.2 (GND), Q2.1 (S), Q2.2 (S), Q2.3 (S), Q4.1 (S), Q4.2 (S), Q4.3 (S), Q6.1 (S), Q6.2 (S), Q6.3 (S), Q8.1 (S), Q8.2 (S), Q8.3 (S), R11.2, R12.2, SW1.3 (ON), U1.5 (GND), U1.16 (GND), U1.20 (SN), U1.21 (SP), U1.25 (EP), U2.5 (GND), U2.16 (GND), U2.20 (SN), U2.21 (SP), U2.25 (EP), U6.5 (GND), U6.6 (GND), U6.8 (GND), U6.9 (GND), U6.13 (GND), U6.14 (GND), U6.17 (EP)
L_A: C16.1, CN1.1, Q1.1 (S), Q1.2 (S), Q1.3 (S), Q2.5 (D), Q2.6 (D), Q2.7 (D), Q2.8 (D), U1.23 (SH2)
L_AVDD: C5.1, U1.6 (VREF), U1.7 (AVDD), U1.12 (IDRIVE)
L_B: CN1.2, Q3.1 (S), Q3.2 (S), Q3.3 (S), Q4.5 (D), Q4.6 (D), Q4.7 (D), Q4.8 (D), R8.2, U1.18 (SH1)
L_CPH: C1.2, U1.3 (CPH)
L_CPL: C1.1, U1.4 (CPL)
L_DVDD: C6.1, U1.8 (DVDD)
L_EN_IN: CN3.4 (L_EN), U1.14 (EN)
L_GH1: Q3.4 (G), U1.17 (GH1)
L_GH2: Q1.4 (G), U1.24 (GH2)
L_GL1: Q4.4 (G), U1.19 (GL1)
L_GL2: Q2.4 (G), U1.22 (GL2)
L_PH_IN: CN3.3 (L_PH), U1.15 (PH)
L_SNUBBER: C16.2, R8.1
L_VCP: C2.1, U1.2 (VCP)
NSLEEP: R5.1, U1.13 (nSLEEP), U2.13 (nSLEEP), U5.2 (COM)
POWER_LED_A: LED2.2 (A), R7.2
PWR_EN: R10.2, R11.1, SW1.2 (COM), U6.16 (EN)
PWR_GATE: C19.1, U6.4 (GATE)
PWR_ILIM: R12.1, U6.7 (ILIM)
R_A: C17.1, CN2.1, Q5.1 (S), Q5.2 (S), Q5.3 (S), Q6.5 (D), Q6.6 (D), Q6.7 (D), Q6.8 (D), U2.23 (SH2)
R_AVDD: C12.1, U2.6 (VREF), U2.7 (AVDD), U2.12 (IDRIVE)
R_B: CN2.2, Q7.1 (S), Q7.2 (S), Q7.3 (S), Q8.5 (D), Q8.6 (D), Q8.7 (D), Q8.8 (D), R9.2, U2.18 (SH1)
R_CPH: C8.2, U2.3 (CPH)
R_CPL: C8.1, U2.4 (CPL)
R_DVDD: C13.1, U2.8 (DVDD)
R_EN_IN: CN3.1 (R_EN), U2.14 (EN)
R_GH1: Q7.4 (G), U2.17 (GH1)
R_GH2: Q5.4 (G), U2.24 (GH2)
R_GL1: Q8.4 (G), U2.19 (GL1)
R_GL2: Q6.4 (G), U2.22 (GL2)
R_PH_IN: CN3.2 (R_PH), U2.15 (PH)
R_SNUBBER: C17.2, R9.1
R_VCP: C9.1, U2.2 (VCP)
VM: C2.2, C3.1, C4.1, C9.2, C10.1, C11.1, C15.1, Q1.5 (D), Q1.6 (D), Q1.7 (D), Q1.8 (D), Q3.5 (D), Q3.6 (D), Q3.7 (D), Q3.8 (D), Q5.5 (D), Q5.6 (D), Q5.7 (D), Q5.8 (D), Q7.5 (D), Q7.6 (D), Q7.7 (D), Q7.8 (D), R1.1, U1.1 (VM), U2.1 (VM), U6.10 (OUT), U6.11 (OUT), U6.12 (OUT)
VM_RAW: C18.1, P2.1 (+12V_RAW), R10.1, U6.1 (IN), U6.2 (IN), U6.3 (IN)

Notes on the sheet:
L MOTOR CHANNEL — ORIGINAL PH/EN DRIVER
SOP Advance: S=1,2,3; G=4; D=5,6,7,8 + thermal pad
Original charge-pump and supply capacitors: all 100nF
Series RC across motor outputs: 100nF + 100 ohm
12V motor: 0.4A rated / 1.8A stall max
R MOTOR CHANNEL — ORIGINAL PH/EN DRIVER
REV B MAIN HIGH-SIDE POWER
SW1 ON = EN low; OFF = divider high
5A nominal limit; about 11ms typical start
OFF chip input standby: 2.5mA typ / 4mA max
COMMON POWER, ENABLE AND ORIGINAL FOUR-SIGNAL INTERFACE
REV B: authorized main power addition; all original values retained; only P2.1 changed to VM_RAW.
CN3 has no ground pin: controller must share ground via power return. 3V3 is a 10k-fed zener node.
VREF/IDRIVE tied to AVDD; SP/SN grounded; nFAULT/SNSOUT/SO NC. U6 adds a shared supply current limit.
Original 100nF bypass values retained: compare TI recommendations before manufacture.

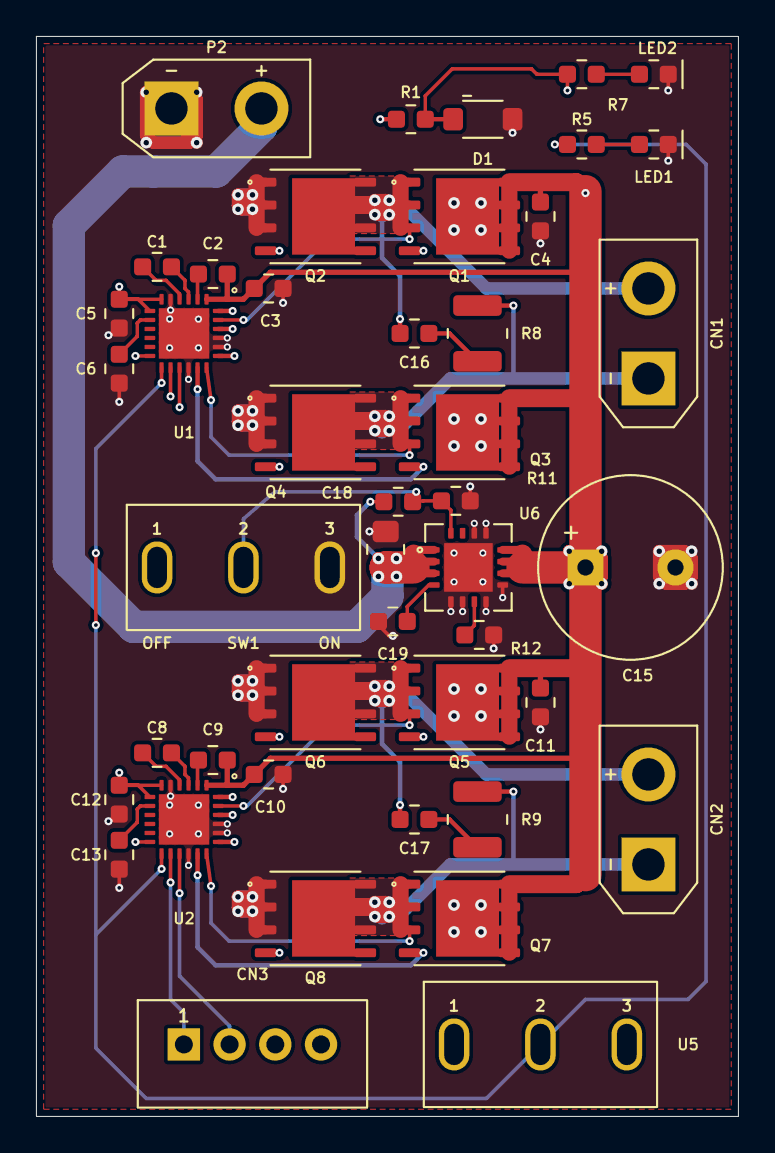
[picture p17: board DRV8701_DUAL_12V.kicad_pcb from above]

Board: 4 copper layers, 39.0 x 60.0 mm, 45 parts (0 on the bottom side), 38 nets.

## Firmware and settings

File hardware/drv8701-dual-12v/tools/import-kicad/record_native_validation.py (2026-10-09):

#!/usr/bin/env python3
"""Check and record the completed native KiCad 5 verification and archive.

This script does not run ERC/DRC, generate an archive, or edit any CAD geometry.
The inputs must be reports and a ZIP produced in the actual KiCad 5 application.
All quantities derive from the final source/legacy geometry and exported netlist.
"""
import argparse
from datetime import datetime
import hashlib
import json
from pathlib import Path
import re
import zipfile
from zoneinfo import ZoneInfo

from audit_legacy_pcb import board_snapshot
from generate_legacy_schematic import read_netlist


def read(path):
    return json.loads(path.read_text())


def sha(path):
    return hashlib.sha256(path.read_bytes()).hexdigest()


def main():
    parser = argparse.ArgumentParser(description=__doc__)
    parser.add_argument("base", type=Path)
    parser.add_argument("legacy", type=Path)
    parser.add_argument("archive", type=Path)
    parser.add_argument("--geometry-report", type=Path)
    args = parser.parse_args()
    base, legacy = args.base.resolve(), args.legacy.resolve()
    geometry_path = args.geometry_report or base/"validation/legacy5_final_pcb_equivalence.json"
    geometry = read(geometry_path)
    assert geometry["passed"] and not geometry["failures"]
    assert geometry["physical_copper_added_by_bridges_mm2"] == 0.0
    pcb = legacy/"DRV8701_DUAL_12V.kicad_pcb"
    assert geometry["source_sha256"] == sha(base/pcb.name), "Geometry proof is for an older source PCB"
    assert geometry["legacy_sha256"] == sha(pcb), "Geometry proof is for an older legacy PCB"
    snapshot, fill = board_snapshot(pcb)
    assert all(x["filled"] and x["vertices"] > 0 for x in fill), "Missing native zone fill"
    assert len(snapshot["tracks"]) == geometry["legacy_track_segments"]
    assert len(snapshot["vias"]) == geometry["legacy_via_count"]
    zone_refill = read(legacy/"validation/legacy5_zone_refill.json")
    assert zone_refill["runtime"].startswith("5.1.")
    assert zone_refill["pcb_sha256"] == sha(pcb), "Native zone evidence is for an older legacy PCB"
    assert zone_refill["all_zones_filled"]
    assert zone_refill["phase_priority_and_direct_connection_verified"]
    assert zone_refill["ground_priority_and_direct_connection_verified"]
    assert len(zone_refill["zones"]) == len(snapshot["zone_boundaries_and_settings"])

    equivalent = read(legacy/"validation/legacy_net_equivalence.json")
    assert equivalent["passed"] and not equivalent["errors"]
    netfile = legacy/"DRV8701_DUAL_12V.net"
    assert equivalent["netlist_sha256"] == sha(netfile), "Netlist audit is for an older export"
    netlist = read_netlist(netfile)
    exporter = netlist.findtext("./design/tool")
    assert exporter and exporter.startswith("Eeschema 5.1."), "Netlist was not exported by real KiCad 5.1"
    runtime = exporter.replace("Eeschema ", "KiCad ", 1)

    drc_path = legacy/"validation/legacy5_drc.rpt"
    drc_text = drc_path.read_text()
    drc_errors = re.findall(r"Found (\d+) DRC errors", drc_text)
    unconnected = re.findall(r"Found (\d+) unconnected pads", drc_text)
    assert drc_errors == ["0"] and unconnected == ["0"], "Native KiCad 5 DRC has violations"
    report_time = re.search(r"Created on ([^*\n]+)", drc_text).group(1).strip()
    erc_path = legacy/"validation/DRV8701_DUAL_12V.erc"
    erc_text = erc_path.read_text()
    erc_counts = re.findall(r"ERC messages:\s*(\d+)\s+Errors\s+(\d+)\s+Warnings\s+(\d+)", erc_text)
    assert erc_counts and all(row == ("0", "0", "0") for row in erc_counts), "Native KiCad 5 ERC has violations"
    drc = dict(errors=0, unconnected_pads=0, report="KiCad_Import_5/validation/legacy5_drc.rpt",
               report_time=report_time, refill_all_zones=True,
               report_all_track_errors=True, test_tracks_against_filled_copper=True)
    erc = dict(errors=0, warnings=0, report="KiCad_Import_5/validation/DRV8701_DUAL_12V.erc")

    entries = []
    with zipfile.ZipFile(args.archive) as archive:
        assert archive.testzip() is None, "Archive CRC check failed"
        assert len(archive.namelist()) == len(set(archive.namelist())), "Duplicate archive entries"
        for name in archive.namelist():
            assert not name.startswith("/") and ".." not in Path(name).parts
            if name.endswith("/"):
                continue
            path = legacy/name
            content = archive.read(name)
            assert path.is_file() and path.read_bytes() == content, "Archive content mismatch: " + name
            entries.append(dict(path=name, bytes=len(content), sha256=hashlib.sha256(content).hexdigest()))
    names = {row["path"] for row in entries}
    required = {"DRV8701_DUAL_12V.pro", "DRV8701_DUAL_12V.sch", pcb.name,
                "DRV8701_DUAL_12V.net", "DRV8701_Custom.lib", "DRV8701_DUAL_12V-cache.lib",
                "fp-lib-table", "sym-lib-table"}
    required.update("DRV8701_Custom.pretty/" + path.name for path in (legacy/"DRV8701_Custom.pretty").glob("*.kicad_mod"))
    assert required <= names, "Archive missing project or library files"
    archive_sha = sha(args.archive)
    counts = dict(components=len(snapshot["footprints"]), pads=len(snapshot["pads"]),
                  segments=len(snapshot["tracks"]), source_segments_retained=geometry["source_track_segments"],
                  explicit_drain_bridge_segments=geometry["added_bridge_segments"],
                  vias=len(snapshot["vias"]), named_nets=equivalent["named_nets"],
                  zones=len(snapshot["zone_boundaries_and_settings"]), outline_edges=len(snapshot["outline"]),
                  copper_layers=snapshot["copper_layers"])
    limits = ["嘉立创 EDA Pro web import has not been executed in a logged-in browser.",
              "Official KiCad import guide says importing regenerates copper; inspect the destination copper and DRC.",
              "KiCad 5 retains layer count and overall board thickness, with detailed stackup supplied separately."]
    actual = dict(runtime=runtime, native_saved_board_sha256=sha(pcb), board_format_version=20171130,
                  board_counts=counts, native_refill={"ZONE_FILLER.Fill": True, "actual5_GUI_DRC_refill": True,
                    "zone_parameters_and_fill_report": "KiCad_Import_5/validation/legacy5_zone_refill.json"},
                  actual5_DRC=drc, actual5_ERC=erc,
                  actual5_netlist=dict(tool=exporter, components=equivalent["components"],
                    named_nets=equivalent["named_nets"], pins=equivalent["physical_pins"],
                    connected_pins=equivalent["connected_pins"], single_node_NC_pins=equivalent["nc_pins"],
                    timestamp_matches=geometry["schematic_component_path_count"]),
                  native_archive=dict(operation="Actual KiCad 5.1 project manager File > Archive Project",
                    zip_sha256=archive_sha, zip_bytes=args.archive.stat().st_size, crc_errors=None, entries=entries),
                  limitations=limits)
    (legacy/"validation/actual_kicad5_validation.json").write_text(json.dumps(actual, ensure_ascii=False, indent=2)+"\n")
    summary = dict(generatedAt=datetime.now(ZoneInfo("Asia/Shanghai")).isoformat(),
        target="JLCEDA Pro web start page > Import KiCad",
        guideUrl="https://prodocs.lceda.cn/cn/import-export/import-kicad/index.html",
        officialGuideVersions=["KiCad 5.1", "KiCad 5.9"], actualRuntime=runtime,
        archiveGenerator=actual["native_archive"]["operation"],
        archive="downloads/DRV8701_12V_KiCad5_Import.zip", archiveBytes=args.archive.stat().st_size,
        archiveSha256=archive_sha, archiveEntries=len(entries), archiveCrcPassed=True,
        allArchiveEntryBytesMatchFinalProject=True, projectEntry="DRV8701_DUAL_12V.pro",
        pcbVersion=20171130, schematicVersion="EESchema Schematic File Version 4", pcbSha256=sha(pcb),
        components=counts["components"], nets=counts["named_nets"], physicalPins=equivalent["physical_pins"],
        actualPadInstances=counts["pads"], originalTrackSegmentsRetained=counts["source_segments_retained"],
        internalPadBridgeSegments=counts["explicit_drain_bridge_segments"], totalSegments=counts["segments"],
        vias=counts["vias"], addedCopperAreaByBridgesMm2=geometry["physical_copper_added_by_bridges_mm2"],
        physicalGeometryAndDesignConnectionsPreserved=True,
        independentGeometryProof="validation/legacy5_final_pcb_equivalence.json",
        actual5Drc=drc, actual5Erc=erc, actual5ExportedNetlistEquivalentToDesign=True,
        actual5ZoneRefill="KiCad_Import_5/validation/legacy5_zone_refill.json",
        actual5ComponentTimestampsMatchPcb=geometry["schematic_component_path_count"],
        realEasyedaWebImportExecuted=False, realEasyedaDrcExecuted=False, hardwareTested=False,
        autorouterUsed=False, limits=limits)
    (base/"validation").mkdir(parents=True, exist_ok=True)
    (base/"validation/kicad5-import-validation.json").write_text(json.dumps(summary, ensure_ascii=False, indent=2)+"\n")
    print(json.dumps(summary, ensure_ascii=False, indent=2))


if __name__ == "__main__":
    main()

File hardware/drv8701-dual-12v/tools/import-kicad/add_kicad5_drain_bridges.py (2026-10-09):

#!/usr/bin/env python3
"""Add explicit SOP Advance drain-pad connections using actual KiCad 5.1.

Run with KiCad 5.1's pcbnew Python binding. --output protects the input.
No routing search is performed: each known drain lead connects along the
footprint's local Y axis to the exposed drain pad, preserving its local X.
Cardinal footprint rotations are supported; already-present bridges remain.
The separate geometry audit proves these segments add no physical copper.
"""
import argparse
import hashlib
import json
from pathlib import Path

import pcbnew


def track_key(track):
    points = sorted([(track.GetStart().x, track.GetStart().y),
                     (track.GetEnd().x, track.GetEnd().y)])
    return tuple(points[0] + points[1]) + (track.GetWidth(), track.GetLayer(), track.GetNetCode())


def bridge_end(module, pad, exposed):
    angle = module.GetOrientationDegrees() % 360
    if angle not in (0, 90, 180, 270):
        raise ValueError("Only cardinal SOP Advance rotations are supported")
    position, center = pad.GetPosition(), exposed.GetPosition()
    return pcbnew.wxPoint(position.x, center.y) if angle in (0, 180) else pcbnew.wxPoint(center.x, position.y)


def main():
    parser = argparse.ArgumentParser(description=__doc__)
    parser.add_argument("input", type=Path)
    parser.add_argument("--output", type=Path, required=True)
    parser.add_argument("--report", type=Path, required=True)
    args = parser.parse_args()
    if args.input.resolve() == args.output.resolve():
        parser.error("--output must differ from the input")
    version = pcbnew.GetBuildVersion()
    if not version.startswith("5.1."):
        parser.error("This script requires an actual KiCad 5.1 pcbnew binding")
    board = pcbnew.LoadBoard(str(args.input))
    original_tracks = [t for t in board.GetTracks() if not isinstance(t, pcbnew.VIA)]
    original_vias = [t for t in board.GetTracks() if isinstance(t, pcbnew.VIA)]
    existing = {track_key(t) for t in original_tracks}
    mosfets = {m.GetReference(): m for m in board.GetModules()
               if str(m.GetFPID().GetLibItemName()) == "TPH1R403NL_SOPAdvance"}
    assert set(mosfets) == {"Q" + str(i) for i in range(1, 9)}, "Expected the eight original motor MOSFETs"
    bridges = []
    already_present = []
    for reference in sorted(mosfets):
        drain_pads = [p for p in mosfets[reference].Pads()
                      if p.GetPadName() in ("5", "6", "7", "8")]
        exposed = max(drain_pads,
                      key=lambda p: p.GetSize().x * p.GetSize().y)
        leads = [p for p in drain_pads if p is not exposed]
        assert len(leads) == 4
        for pad in leads:
            assert pad.GetNetCode() == exposed.GetNetCode()
            start = pad.GetPosition()
            end = bridge_end(mosfets[reference], pad, exposed)
            track = pcbnew.TRACK(board)
            track.SetStart(start)
            track.SetEnd(end)
            track.SetWidth(250000)
            track.SetLayer(pcbnew.F_Cu)
            track.SetNetCode(pad.GetNetCode())
            row = {
                "reference": reference, "lead_pad": pad.GetPadName(),
                "net": pad.GetNetname(), "layer": "F.Cu", "width_mm": 0.25,
                "start_mm": [start.x / 1e6, start.y / 1e6],
                "end_mm": [end.x / 1e6, end.y / 1e6],
            }
            if track_key(track) in existing:
                already_present.append(row)
            else:
                board.Add(track)
                existing.add(track_key(track))
                bridges.append(row)
    assert len(bridges) + len(already_present) == sum(
        len([pad for pad in module.Pads() if pad.GetPadName() in ("5", "6", "7", "8")]) - 1
        for module in mosfets.values())
    assert len(list(board.GetTracks())) == len(original_tracks) + len(original_vias) + len(bridges)
    assert pcbnew.ZONE_FILLER(board).Fill(board.Zones())
    args.output.parent.mkdir(parents=True, exist_ok=True)
    assert pcbnew.SaveBoard(str(args.output), board)
    args.report.parent.mkdir(parents=True, exist_ok=True)
    args.report.write_text(json.dumps({
        "runtime": version,
        "method": "Explicit drain lead to exposed-pad connections along the local footprint Y axis",
        "autorouting_used": False, "pathfinding_used": False,
        "original_segments": len(original_tracks), "additional_segments": len(bridges),
        "total_segments": len(original_tracks) + len(bridges), "vias": len(original_vias),
        "bridges": bridges, "already_present_bridges": already_present,
        "input_sha256": hashlib.sha256(args.input.read_bytes()).hexdigest(),
        "output_sha256": hashlib.sha256(args.output.read_bytes()).hexdigest(),
        "verification": "Actual KiCad 5.1 GUI DRC and independent copper containment required",
    }, indent=2, ensure_ascii=False) + "\n")


if __name__ == "__main__":
    main()

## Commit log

2026-10-08 Add DRV8701 dual motor EasyEDA Pro project
    Include the complete native project, editable CAD sources, PCB previews, BOM, validation records and download archive. Preserve original circuit values and manual routing, with client and datasheet v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
    [DRV8701_DUAL_12V.kicad_pcb, DRV8701_DUAL_12V.kicad_sch, components.csv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]
2026-10-09 Add KiCad 5.1 import package for EasyEDA Pro web
    Provide a native KiCad 5.1 archive for the web import workflow, with full project libraries and corrected opening instructions. Validate the package using actual KiCad 5.1.9 ERC, DRC and exported netlist checks; preserve source geometry with 32 drain connections contained in existing pad copper.
    Include the retrieved Toshiba exact-model manufacturer datasheet and refreshed verification records. Actual EasyEDA web import remains unverified and destination copper refill checks are documented.
    [DRV8701_DUAL_12V.kicad_pcb, DRV8701_DUAL_12V.sch, procurement_notes.csv]
2026-10-09 Rework DRV8701 Rev B power control and manual PCB layout
    [DRV8701_DUAL_12V.kicad_pcb, DRV8701_DUAL_12V.kicad_sch, DRV8701_DUAL_12V.sch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]
